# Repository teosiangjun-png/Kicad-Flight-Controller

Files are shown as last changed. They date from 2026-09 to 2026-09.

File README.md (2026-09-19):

# Custom STM32F722 Flight Controller (Rev 1 Prototype)

A custom, bare-metal quadcopter flight controller engineered around the STMicroelectronics STM32F722 MCU running Betaflight.

This repository documents the KiCad schematics, PCB layout files, custom Betaflight target modifications, and a post-mortem technical analysis of bringing up a custom board through non-ideal hardware constraints and silicon-level clock workarounds.

---

## Technical Specifications

- **Microcontroller:** STM32F722RET6 / STM32F722 (ARM Cortex-M7 @ 216 MHz)
- **Target Firmware:** Betaflight (Custom fork derived from `BETAFPVF722`)
- **Physical Footprint:** 36 × 36 mm standard mounting pattern
- **Power Architecture:** Direct LiPo battery input with on-board buck/LDO stages for 5V and 3.3V rails
- **Peripheral Bus:** SPI for IMU communication, hardware UARTs for receiver and telemetry links

---

## Hardware Overview

### PCB Layout

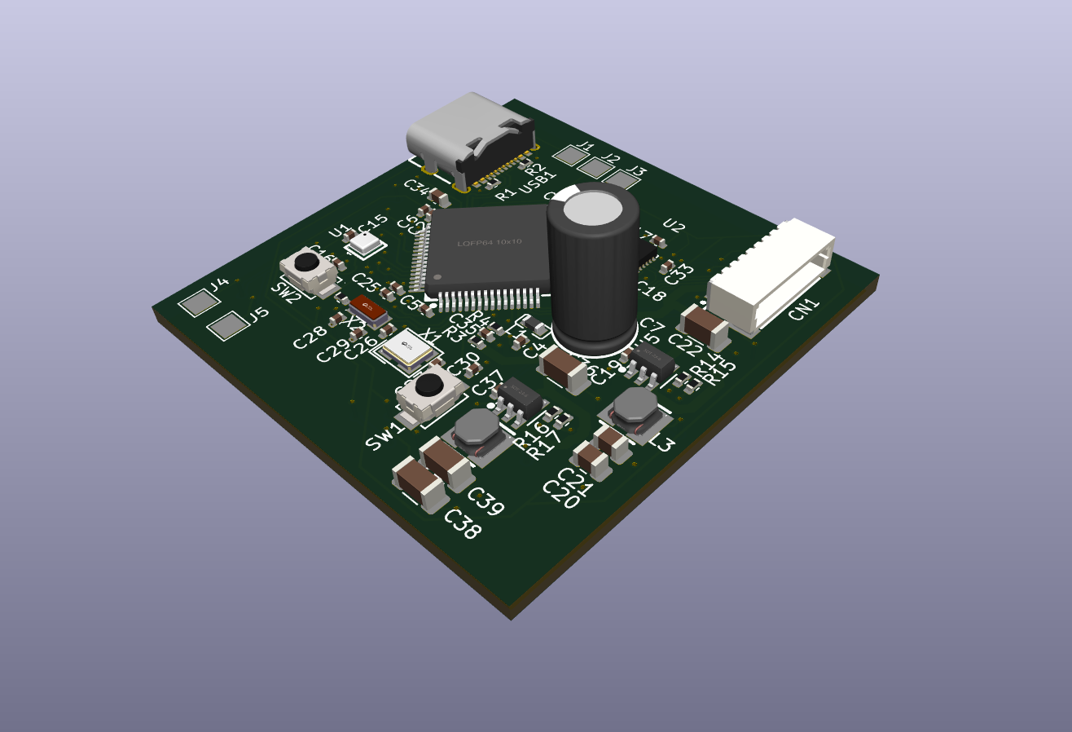
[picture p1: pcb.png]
PCB Layout


### Schematic

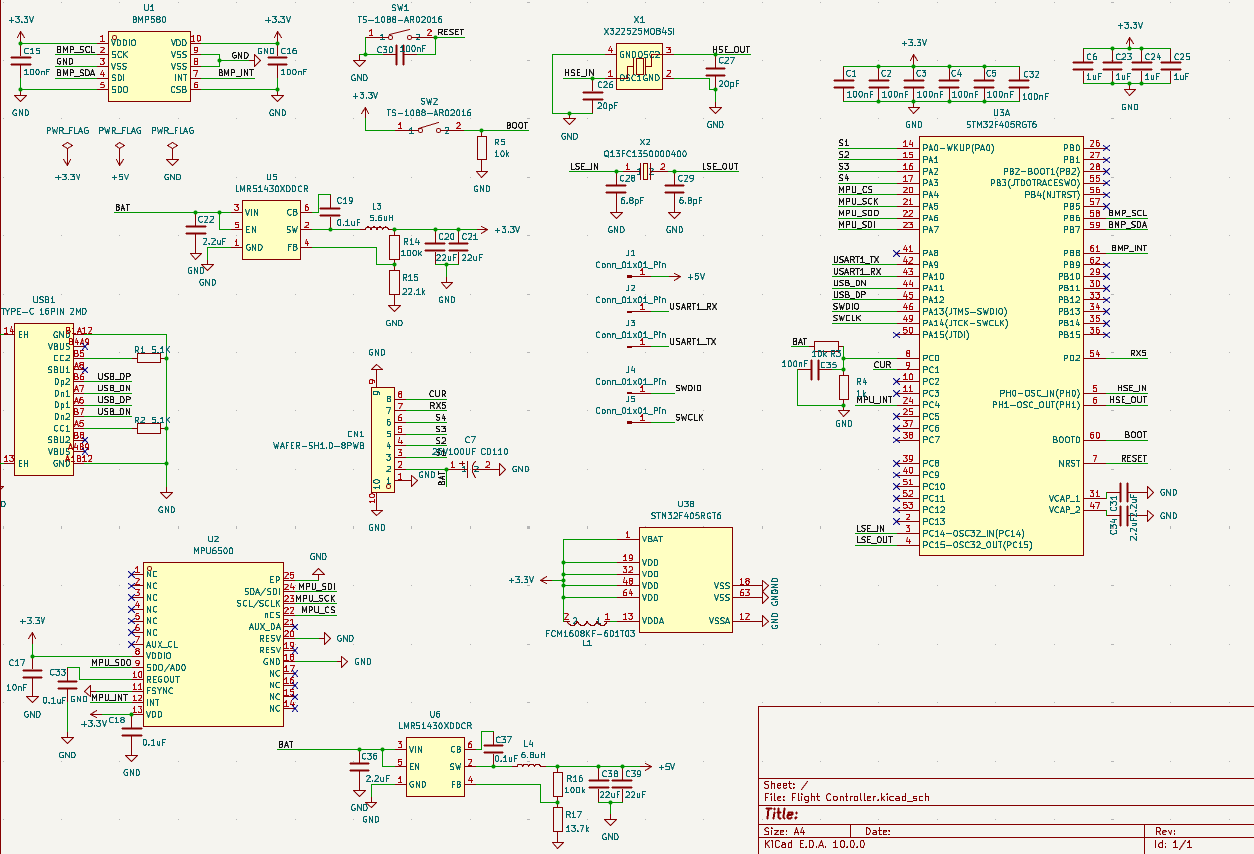
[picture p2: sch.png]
Schematic


---

## Repository Structure

```text
├── hardware/
│   ├── schematics/        # KiCad schematics (.kicad_sch)
│   ├── pcb/               # KiCad PCB layout and routing (.kicad_pcb)
│   └── gerbers/           # Fabrication and drill outputs
├── firmware/
│   ├── patches/           # Clock tree and pinout diffs against Betaflight master
│   └── target/            # Custom target configuration and pin mappings
└── docs/
    └── post-mortem.md     # Detailed engineering failure analysis and bring-up logs
```

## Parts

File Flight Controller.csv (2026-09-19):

Reference | Qty | Value | DNP | Exclude from BOM | Exclude from Board | Footprint | Datasheet
C1,C2,C3,C4,C5,C15,C16,C30,C32,C35 | 10 | 100nF |  |  |  | Capacitor_SMD:C_0402_1005Metric
C6,C23,C24,C25 | 4 | 1uF |  |  |  | Capacitor_SMD:C_0402_1005Metric
C7 | 1 | 25V100UF CD110 |  |  |  | easyeda2kicad:CAP-TH_BD6.3-P2.50-D0.5-FD | https://www.lcsc.com/datasheet/C2960218.pdf
C17 | 1 | 10nF |  |  |  | Capacitor_SMD:C_0402_1005Metric
C18,C19,C33,C37 | 4 | 0.1uF |  |  |  | Capacitor_SMD:C_0402_1005Metric
C20,C21 | 2 | 22uF |  |  |  | Capacitor_SMD:C_0805_2012Metric
C22,C36 | 2 | 2.2uF |  |  |  | Capacitor_SMD:C_1206_3216Metric
C26,C27 | 2 | 20pF |  |  |  | Capacitor_SMD:C_0402_1005Metric
C28,C29 | 2 | 6.8pF |  |  |  | Capacitor_SMD:C_0402_1005Metric
C31,C34 | 2 | 2.2uF |  |  |  | Capacitor_SMD:C_0603_1608Metric
C38,C39 | 2 | 22uF |  |  |  | Capacitor_SMD:C_1206_3216Metric
CN1 | 1 | WAFER-SH1.0-8PWB |  |  |  | easyeda2kicad:CONN-SMD_8P-P1.00_XUNPU_WAFER-SH1.0-8PWB | https://www.lcsc.com/datasheet/C3029347.pdf
J1,J2,J3,J4,J5 | 5 | Conn_01x01_Pin |  |  |  | TestPoint:TestPoint_THTPad_2.0x2.0mm_Drill1.0mm
L1 | 1 | FCM1608KF-601T03 |  |  |  | easyeda2kicad:L0603 | https://lcsc.com/product-detail/Multilayer-Ceramic-Capacitors_600R-25-at100MHz_C141723.html
L3 | 1 | 5.6uH |  |  |  | easyeda2kicad:IND-SMD_L3.0-W3.0
L4 | 1 | 6.8uH |  |  |  | easyeda2kicad:IND-SMD_L3.0-W3.0
R1,R2 | 2 | 5.1K |  |  |  | Resistor_SMD:R_0402_1005Metric
R3,R5 | 2 | 10k |  |  |  | Resistor_SMD:R_0402_1005Metric
R4 | 1 | 1k |  |  |  | Resistor_SMD:R_0402_1005Metric
R14,R16 | 2 | 100k |  |  |  | Resistor_SMD:R_0402_1005Metric
R15 | 1 | 22.1k |  |  |  | Resistor_SMD:R_0402_1005Metric
R17 | 1 | 13.7k |  |  |  | Resistor_SMD:R_0402_1005Metric
SW1,SW2 | 2 | TS-1088-AR02016 |  |  |  | easyeda2kicad:SW-SMD_L3.9-W3.0-P4.45 | https://lcsc.com/product-detail/Tactile-Switches_XUNPU-TS-1088-AR02016_C720477.html
U1 | 1 | BMP580 |  |  |  | easyeda2kicad:LGA-10_L2.0-W2.0-P0.50-TL_BMP580 | https://www.lcsc.com/datasheet/C22391138.pdf
U2 | 1 | MPU6500 |  |  |  | easyeda2kicad:QFN-24_L3.0-W3.0-P0.40-BL-EP | https://lcsc.com/product-detail/Processors-Microcontrollers_InvenSense_MPU6500_MPU6500_C50278.html
U3 | 1 | STM32F405RGT6 |  |  |  | easyeda2kicad:LQFP-64_L10.0-W10.0-P0.50-LS12.0-BL | https://lcsc.com/product-detail/ST-Microelectronics_STMicroelectronics_STM32F405RGT6_STM32F405RGT6_C15742.html
U5,U6 | 2 | LMR51430XDDCR |  |  |  | easyeda2kicad:SOT-23-6_L2.9-W1.6-P0.95-LS2.8-BL | https://www.lcsc.com/datasheet/C5185863.pdf
USB1 | 1 | TYPE-C 16PIN 2MD |  |  |  | easyeda2kicad:USB-C-SMD_TYPE-C-16PIN-2MD-073 | https://www.lcsc.com/datasheet/C2765186.pdf
X1 | 1 | X322525MOB4SI |  |  |  | easyeda2kicad:CRYSTAL-SMD_4P-L3.2-W2.5-BL | https://lcsc.com/product-detail/SMD-Crystals_YSX321SL-25MHZ-12PF-10PPM-40-85_C9006.html
X2 | 1 | Q13FC1350000400 |  |  |  | easyeda2kicad:FC-135R_L3.2-W1.5 | https://lcsc.com/product-detail/SMD-Crystals_EPSON_Q13FC1350000400_32-768KHz-20ppm-12-5pF_C32346.html

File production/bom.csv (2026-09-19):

Designator | Footprint | Quantity | Value | LCSC Part #
C1, C15, C16, C2, C3, C30, C32, C35, C4, C5 | 0402 | 10 | 100nF
C17 | 0402 | 1 | 10nF
C18, C19, C33, C37 | 0402 | 4 | 0.1uF
C20, C21 | 0805 | 2 | 22uF
C22, C36 | 1206 | 2 | 2.2uF
C23, C24, C25, C6 | 0402 | 4 | 1uF
C26, C27 | 0402 | 2 | 20pF
C28, C29 | 0402 | 2 | 6.8pF
C31, C34 | 0603 | 2 | 2.2uF
C38, C39 | 1206 | 2 | 22uF
C7 | CAP-TH_BD6.3-P2.50-D0.5-FD | 1 | 25V100UF CD110 | C2960218
CN1 | CONN-SMD_8P-P1.00_XUNPU_WAFER-SH1.0-8PWB | 1 | WAFER-SH1.0-8PWB | C3029347
J1, J2, J3, J4, J5 | TestPoint_THTPad_2.0x2.0mm_Drill1.0mm | 5 | Conn_01x01_Pin
L1 | L0603 | 1 | FCM1608KF-601T03 | C141723
L3 | IND-SMD_L3.0-W3.0 | 1 | 5.6uH | C18236327
L4 | IND-SMD_L3.0-W3.0 | 1 | 6.8uH | C18236327
R1, R2 | 0402 | 2 | 5.1K
R14, R16 | 0402 | 2 | 100k
R15 | 0402 | 1 | 22.1k
R17 | 0402 | 1 | 13.7k
R3, R5 | 0402 | 2 | 10k
R4 | 0402 | 1 | 1k
SW1, SW2 | SW-SMD_L3.9-W3.0-P4.45 | 2 | TS-1088-AR02016 | C720477
U1 | LGA-10_L2.0-W2.0-P0.50-TL_BMP580 | 1 | BMP580 | C22391138
U2 | QFN-24_L3.0-W3.0-P0.40-BL-EP | 1 | MPU6500 | C50278
U3 | LQFP-64_L10.0-W10.0-P0.50-LS12.0-BL | 1 | STM32F405RGT6 | C118207
U5, U6 | SOT-23-6_L2.9-W1.6-P0.95-LS2.8-BL | 2 | LMR51430XDDCR | C5185863
USB1 | USB-C-SMD_TYPE-C-16PIN-2MD-073 | 1 | TYPE-C 16PIN 2MD | C2765186
X1 | CRYSTAL-SMD_4P-L3.2-W2.5-BL | 1 | X322525MOB4SI | C9006
X2 | FC-135R_L3.2-W1.5 | 1 | Q13FC1350000400 | C32346

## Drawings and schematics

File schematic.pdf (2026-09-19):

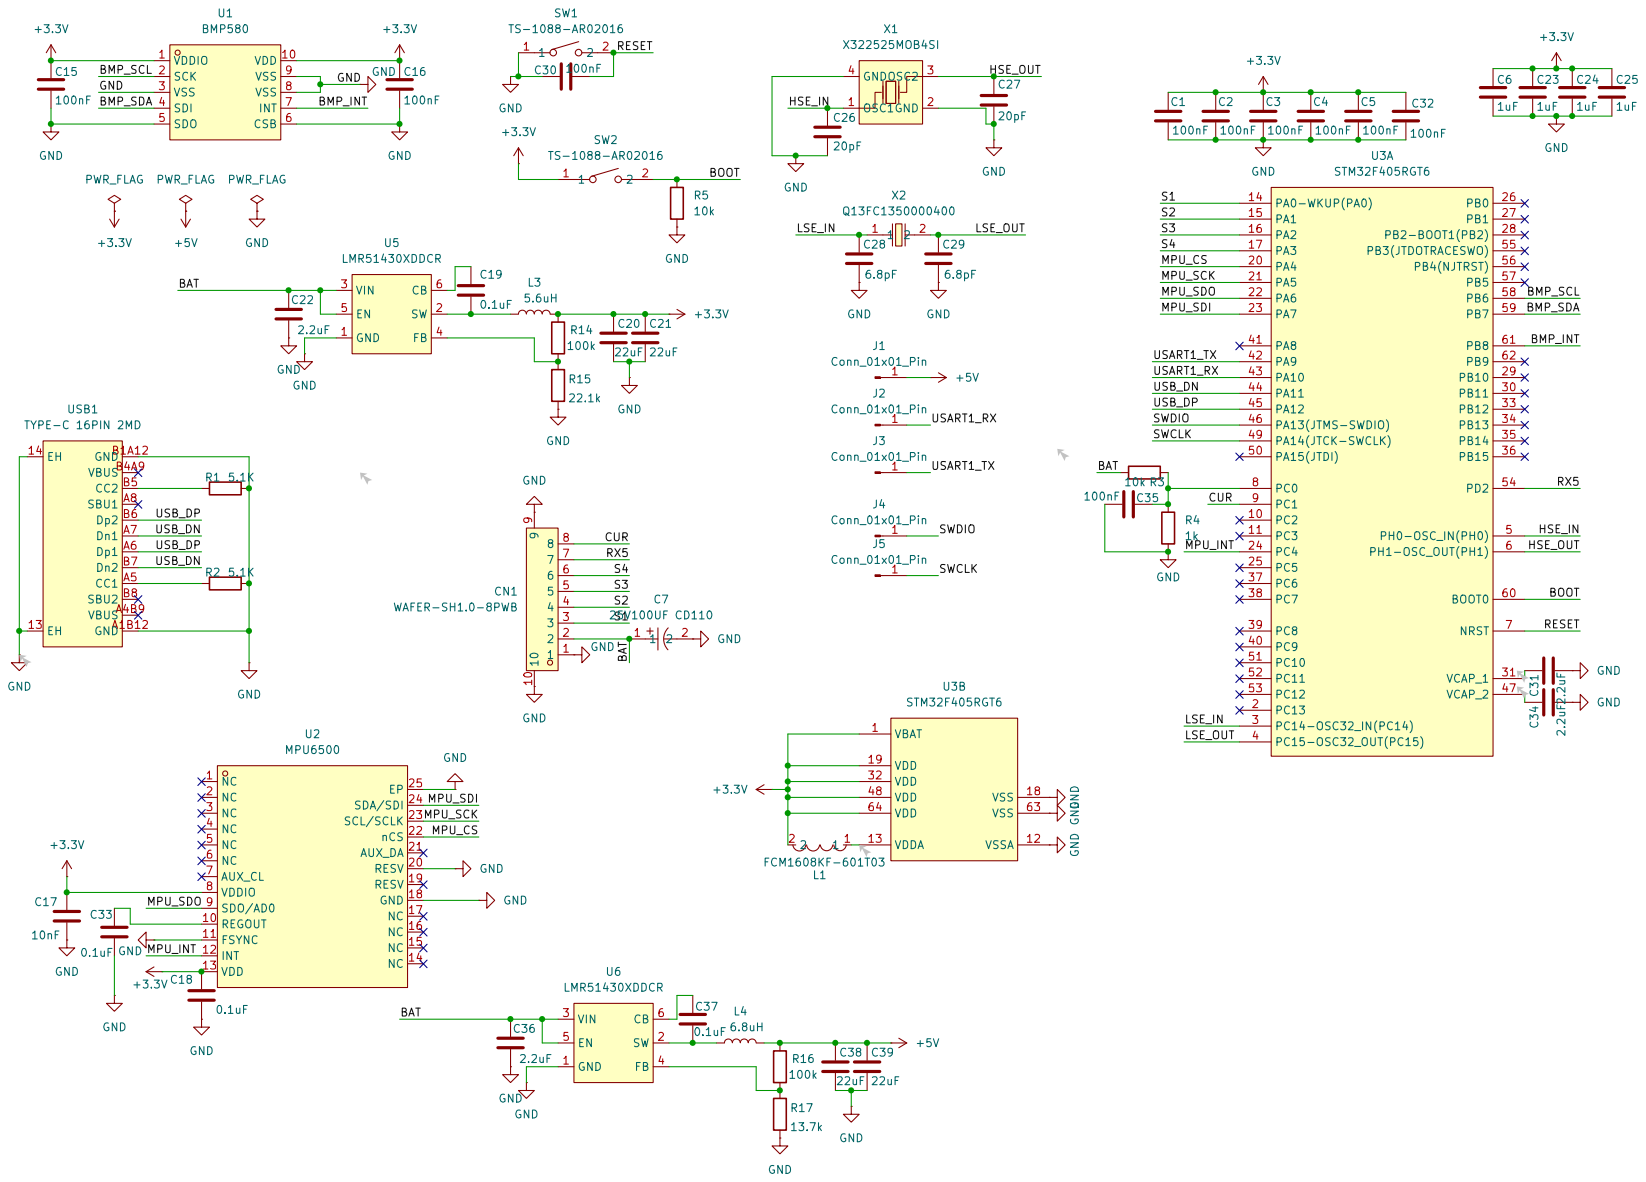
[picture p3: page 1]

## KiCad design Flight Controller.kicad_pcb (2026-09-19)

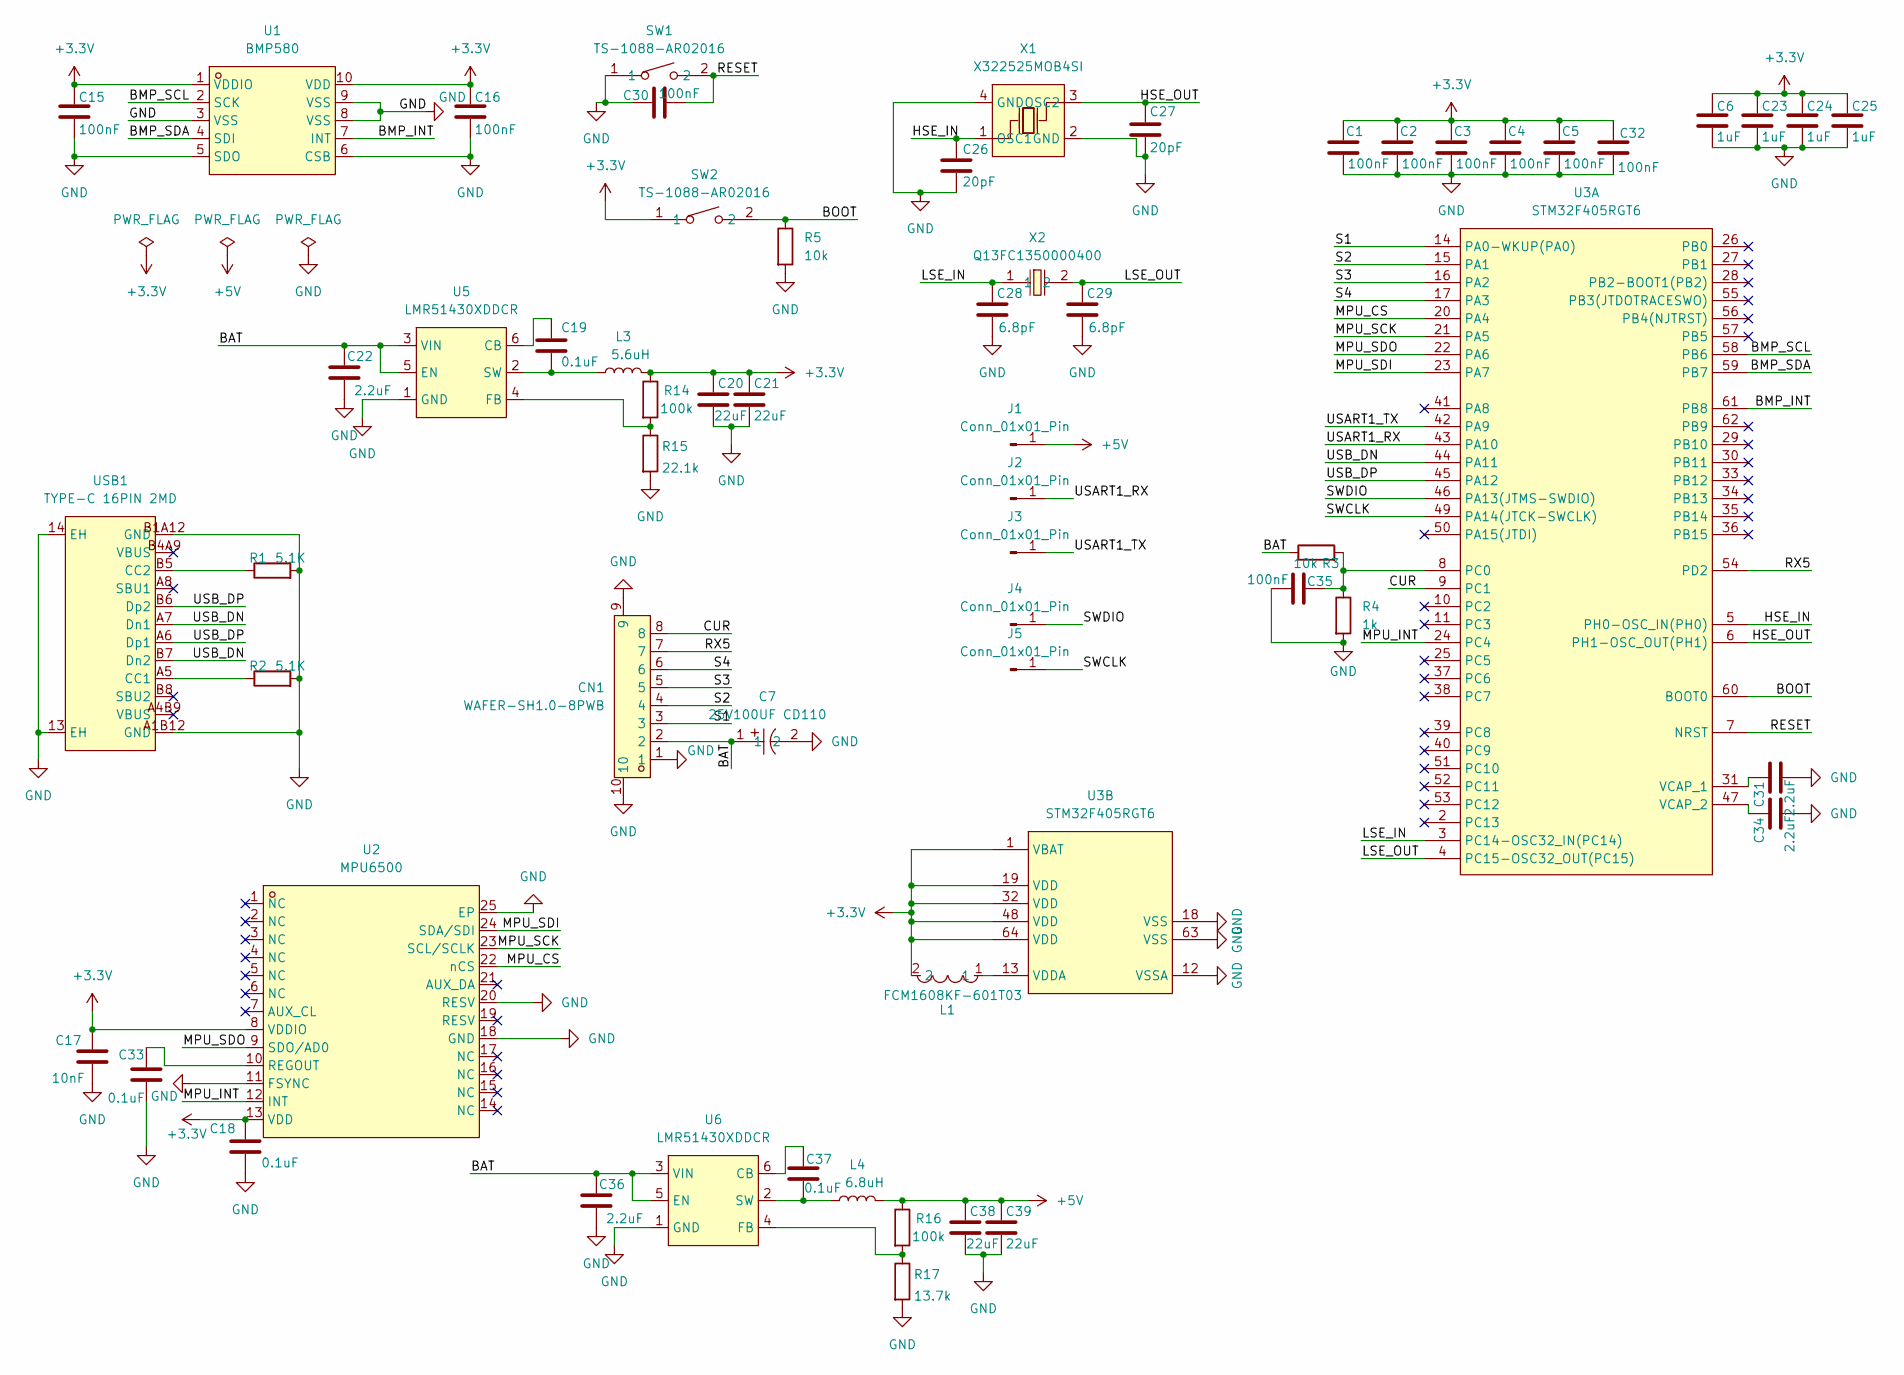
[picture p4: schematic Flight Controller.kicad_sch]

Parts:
C1, C2, C3, C4, C5, C15, C16, C30, C32, C35: 100nF; C_0402_1005Metric
C6, C23, C24, C25: 1uF; C_0402_1005Metric
C7: 25V100UF CD110; CAP-TH_BD6.3-P2.50-D0.5-FD; MPN 25V100uF CD110; LCSC Part C2960218
C17: 10nF; C_0402_1005Metric
C18, C19, C33, C37: 0.1uF; C_0402_1005Metric
C20, C21: 22uF; C_0805_2012Metric
C22, C36: 2.2uF; C_1206_3216Metric
C26, C27: 20pF; C_0402_1005Metric
C28, C29: 6.8pF; C_0402_1005Metric
C31, C34: 2.2uF; C_0603_1608Metric
C38, C39: 22uF; C_1206_3216Metric
CN1: WAFER-SH1.0-8PWB; CONN-SMD_8P-P1.00_XUNPU_WAFER-SH1.0-8PWB; MPN WAFER-SH1.0-8PWB; LCSC Part C3029347
J1, J2, J3, J4, J5: Conn_01x01_Pin; TestPoint_THTPad_2.0x2.0mm_Drill1.0mm
L1: FCM1608KF-601T03; L0603; MPN FCM1608KF-601T03; LCSC Part C141723
L3: 5.6uH; IND-SMD_L3.0-W3.0
L4: 6.8uH; IND-SMD_L3.0-W3.0
R1, R2: 5.1K; R_0402_1005Metric
R3, R5: 10k; R_0402_1005Metric
R4: 1k; R_0402_1005Metric
R14, R16: 100k; R_0402_1005Metric
R15: 22.1k; R_0402_1005Metric
R17: 13.7k; R_0402_1005Metric
SW1, SW2: TS-1088-AR02016; SW-SMD_L3.9-W3.0-P4.45; MPN TS-1088-AR02016; LCSC Part C720477
U1: BMP580; LGA-10_L2.0-W2.0-P0.50-TL_BMP580; MPN BMP580; LCSC Part C22391138
U2: MPU6500; QFN-24_L3.0-W3.0-P0.40-BL-EP; MPN MPU-6500; LCSC Part C50278
U3: STM32F405RGT6; LQFP-64_L10.0-W10.0-P0.50-LS12.0-BL; MPN STM32F405RGT6; LCSC Part C15742
U5, U6: LMR51430XDDCR; SOT-23-6_L2.9-W1.6-P0.95-LS2.8-BL; MPN LMR51430XDDCR; LCSC Part C5185863
USB1: TYPE-C 16PIN 2MD; USB-C-SMD_TYPE-C-16PIN-2MD-073; MPN TYPE-C 16PIN 2MD(073); LCSC Part C2765186
X1: X322525MOB4SI; CRYSTAL-SMD_4P-L3.2-W2.5-BL; MPN X322525MOB4SI; LCSC Part C9006
X2: Q13FC1350000400; FC-135R_L3.2-W1.5; MPN Q13FC13500004; LCSC Part C32346

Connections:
+3.3V: C1.1, C2.1, C3.1, C4.1, C5.1, C6.1, C15.1, C16.1, C17.1, C18.1, C20.1, C21.1, C23.1, C24.1, C25.1, C32.1, L1.2, L3.2, R14.1, SW2.1, U1.1 (VDDIO), U1.10 (VDD), U2.8 (VDDIO), U2.13 (VDD), U3.1 (VBAT), U3.19 (VDD), U3.32 (VDD), U3.48 (VDD), U3.64 (VDD)
+5V: C38.1, C39.1, J1.1 (Pin_1_1), L4.2, R16.1
/BAT: C7.1, C22.1, C36.1, CN1.2, R3.1, U5.3 (VIN), U5.5 (EN), U6.3 (VIN), U6.5 (EN)
/BMP_INT: U1.7 (INT), U3.61 (PB8)
/BMP_SCL: U1.2 (SCK), U3.58 (PB6)
/BMP_SDA: U1.4 (SDI), U3.59 (PB7)
/BOOT: R5.1, SW2.2, U3.60 (BOOT0)
/CUR: CN1.8, U3.9 (PC1)
/HSE_IN: C26.1, U3.5 (PH0-OSC_IN(PH0)), X1.1 (OSC1)
/HSE_OUT: C27.1, U3.6 (PH1-OSC_OUT(PH1)), X1.3 (OSC2)
/LSE_IN: C28.1, U3.3 (PC14-OSC32_IN(PC14)), X2.1
/LSE_OUT: C29.1, U3.4 (PC15-OSC32_OUT(PC15)), X2.2
/MPU_CS: U2.22 (nCS), U3.20 (PA4)
/MPU_INT: U2.12 (INT), U3.24 (PC4)
/MPU_SCK: U2.23 (SCL/SCLK), U3.21 (PA5)
/MPU_SDI: U2.24 (SDA/SDI), U3.23 (PA7)
/MPU_SDO: U2.9 (SDO/AD0), U3.22 (PA6)
/RESET: C30.2, SW1.2, U3.7 (NRST)
/RX5: CN1.7, U3.54 (PD2)
/S1: CN1.3, U3.14 (PA0-WKUP(PA0))
/S2: CN1.4, U3.15 (PA1)
/S3: CN1.5, U3.16 (PA2)
/S4: CN1.6, U3.17 (PA3)
/SWCLK: J5.1 (Pin_1_1), U3.49 (PA14(JTCK-SWCLK))
/SWDIO: J4.1 (Pin_1_1), U3.46 (PA13(JTMS-SWDIO))
/USART1_RX: J2.1 (Pin_1_1), U3.43 (PA10)
/USART1_TX: J3.1 (Pin_1_1), U3.42 (PA9)
/USB_DN: U3.44 (PA11), USB1.A7 (Dn1), USB1.B7 (Dn2)
/USB_DP: U3.45 (PA12), USB1.A6 (Dp1), USB1.B6 (Dp2)
GND: C1.2, C2.2, C3.2, C4.2, C5.2, C6.2, C7.2, C15.2, C16.2, C17.2, C18.2, C20.2, C21.2, C22.2, C23.2, C24.2, C25.2, C26.2, C27.2, C28.2, C29.2, C30.1, C31.2, C32.2, C33.2, C34.2, C35.1, C36.2, C38.2, C39.2, CN1.1, CN1.9, CN1.10, R1.2, R2.2, R4.2, R5.2, R15.2, R17.2, SW1.1, U1.3 (VSS), U1.5 (SDO), U1.6 (CSB), U1.8 (VSS), U1.9 (VSS), U2.11 (FSYNC), U2.18 (GND), U2.20 (RESV), U2.25 (EP), U3.12 (VSSA), U3.18 (VSS), U3.63 (VSS), U5.1 (GND), U6.1 (GND), USB1.13 (EH), USB1.14 (EH), USB1.A1B12 (GND), USB1.B1A12 (GND), X1.2 (GND), X1.4 (GND)
unnamed: C33.1, U2.10 (REGOUT)
unnamed: C35.2, R3.2, R4.1, U3.8 (PC0)
unnamed: C31.1, U3.31 (VCAP_1)
unnamed: C34.1, U3.47 (VCAP_2)
unnamed: L1.1, U3.13 (VDDA)
unnamed: C19.1, U5.6 (CB)
unnamed: R14.2, R15.1, U5.4 (FB)
unnamed: C19.2, L3.1, U5.2 (SW)
unnamed: C37.1, U6.6 (CB)
unnamed: R16.2, R17.1, U6.4 (FB)
unnamed: C37.2, L4.1, U6.2 (SW)
unnamed: R2.1, USB1.A5 (CC1)
unnamed: R1.1, USB1.B5 (CC2)

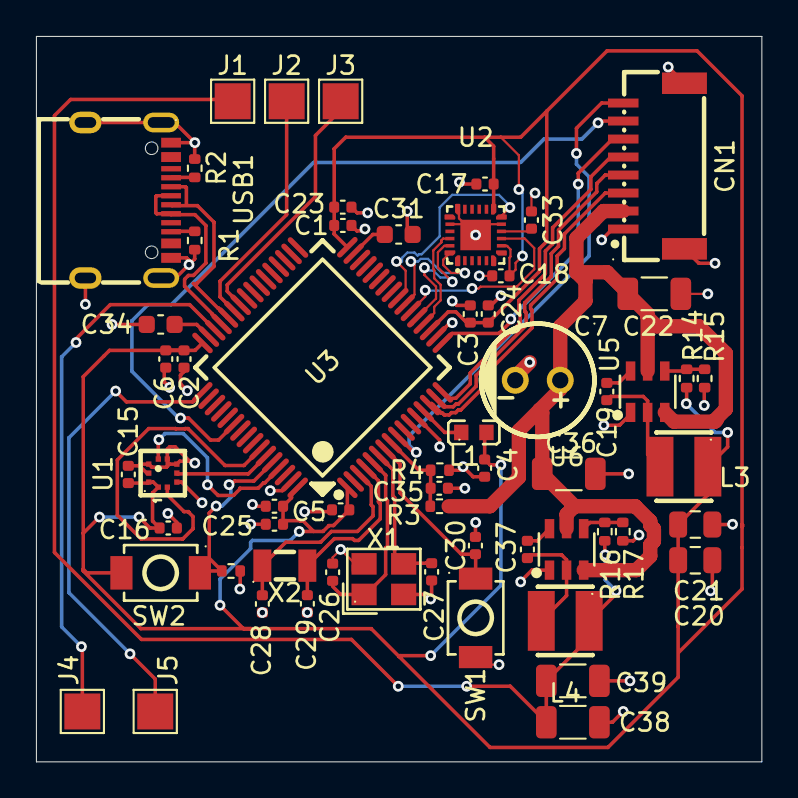
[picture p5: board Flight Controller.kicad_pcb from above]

Board: 2 copper layers, 40.3 x 40.3 mm, 60 parts (0 on the bottom side), 43 nets.

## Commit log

2026-09-19 Initial commit: Rev 1 Flight Controller hardware and documentation
    [Flight Controller.csv, Flight Controller.kicad_pcb, Flight Controller.kicad_sch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]
2026-09-19 Add schematic image asset
2026-09-19 Fix: correct MCU part number in BOM
    [Flight Controller.csv]
